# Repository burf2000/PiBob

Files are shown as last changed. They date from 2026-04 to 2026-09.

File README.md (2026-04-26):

# PiBob

> **Work in Progress** — This is v0.1. The design and software are functional but still evolving. Expect rough edges, and contributions are very welcome!

A cheap, 3D-printable robot you can build for under £100. Powered by a Raspberry Pi with dual arms and a head, controlled via a web interface. PiBob uses an Adafruit PCA9685 servo hat to drive 10 servos, with a Flask web app for real-time control and a live camera feed.

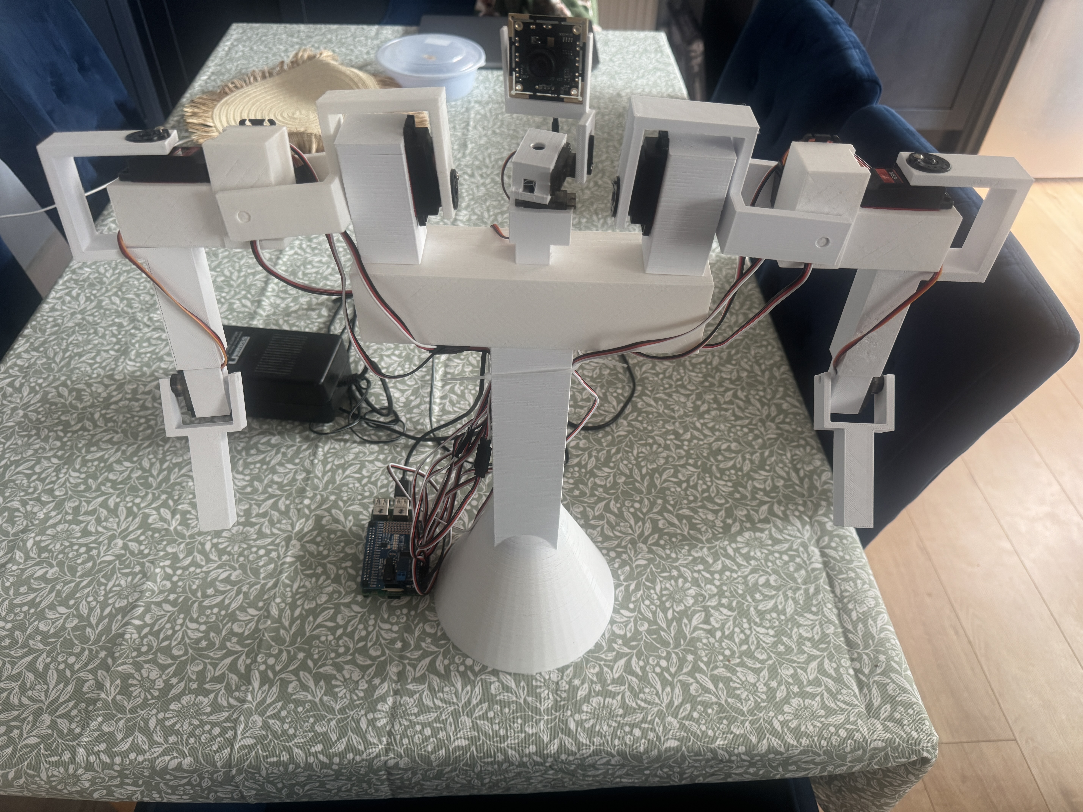
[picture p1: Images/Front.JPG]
PiBob Front View

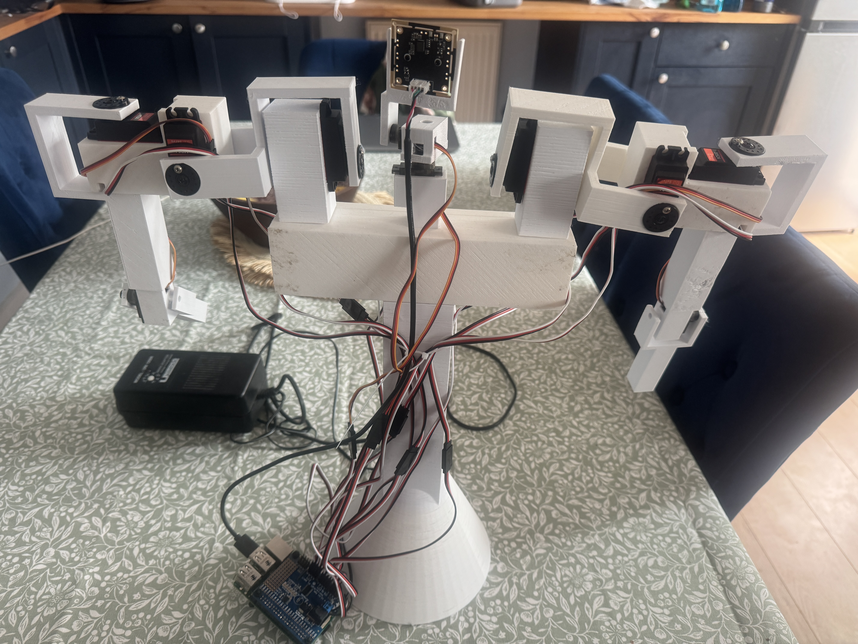
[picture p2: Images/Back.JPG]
PiBob Back View


## Features

- **Web UI** — real-time sliders, enable/disable, reverse direction, pulse width tuning
- **Live camera feed** — streamed directly to the web interface
- **16-channel control** — servo, continuous rotation, or raw PWM modes per channel
- **Safe limits** — configurable min/max per channel, persisted to `config.json`
- **Presets** — save and load servo positions
- **Gestures** — pre-programmed movements with smooth interpolation:
  Wave, Point, Run, Scared, Angry, Celebrate, Shrug, Dab, Fight, Dance
- **Sweep test** — automatically sweep all servos through their range
- **PWM frequency** — adjustable from 24–1526 Hz

## Hardware

See [BOM.md](BOM.md) for the full bill of materials. Key components:

- Raspberry Pi (any model with I2C and USB)
- Adafruit PCA9685 16-channel servo HAT
- 4x Miuzei 9G micro servos (head + smaller joints)
- 6x Miuzei DS3218MG 20KG digital servos (arm joints)
- 1x USB camera module
- 3D printed parts (STL files included)

### Channel Mapping

| Channel | Joint | Notes |
|---|---|---|
| CH2 | Head Rotation | Left/right, full range (0-180) |
| CH3 | Head Tilt | Up/down (50-140) |
| CH4 | Right Bicep | 90 = straight, 180 = fully bent |
| CH5 | Right Arm Rotation | Reversed, side-to-side |
| CH6 | Right Shoulder Lift | Reversed, chicken wing style |
| CH7 | Right Shoulder Rotation | Reversed, arm up/down front |
| CH8 | Left Bicep | Reversed, mirrors right |
| CH9 | Left Arm Rotation | Side-to-side |
| CH10 | Left Shoulder Lift | Chicken wing style |
| CH11 | Left Shoulder Rotation | Arm up/down front |

## 3D Printing & Assembly

All STL files are in the [`STL/`](STL/) folder. Parts were designed in TinkerCAD. PLA works fine for all parts.

### Print List

| Part | File | Qty |
|---|---|-----|
| Desktop Base | `Desktop-Base.stl` | 1 |
| Shoulder Beam | `Shoulder-Beam.stl` | 1 |
| Head Bottom Servo Holder | `Head-BottomServoHolder.stl` | 1 |
| Head Middle Servo Holder | `Head-MiddleServoHolder.stl` | 1 |
| Head Camera Holder | `Head-CameraHolder.stl` | 1 |
| Shoulder Top Servo Holder | `Shoulder-Top-ServoHolder.stl` | 2 |
| Shoulder Left Bracket | `Shoulder-Left-Bracket.stl` | 1 |
| Shoulder Right Bracket | `Shoulder-Right-Bracket.stl` | 1 |
| Shoulder Left Servo Holder | `Shoulder-Left-ServoHolder.stl` | 1 |
| Shoulder Right Servo Holder | `Shoulder-Right-ServoHolder.stl` | 1 |
| Arm Bicep | `Arm-Bicep.stl` | 2 |
| Arm Elbow | `Arm-Elbow.stl` | 2 |
| Arm Forearm | `Arm-Forearm.stl` | 2 |

### Assembly: Body

1. Print `Desktop-Base.stl` — this is the main base of the robot
2. Place `Shoulder-Beam.stl` on top of the base to form the main body

### Assembly: Head

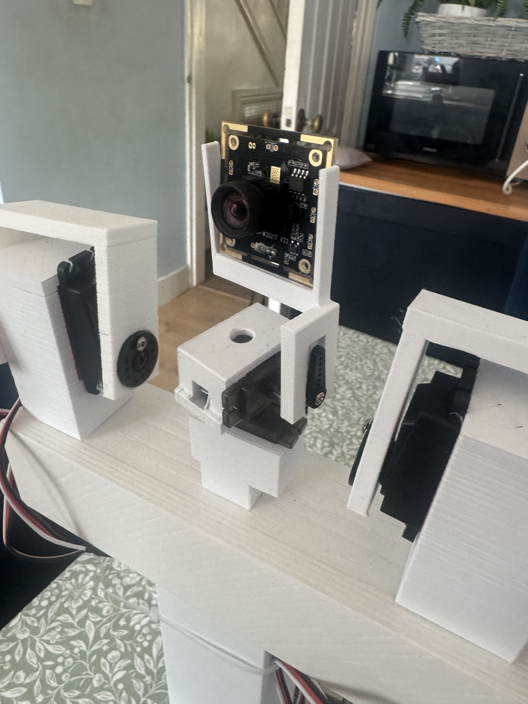
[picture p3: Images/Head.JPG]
Head assembly


1. Fit a small servo into `Head-BottomServoHolder.stl`, then push it into the top of `Shoulder-Beam.stl`
2. Fit another small servo to `Head-MiddleServoHolder.stl`, then attach it to `Head-BottomServoHolder.stl`
3. Slide the USB camera into `Head-CameraHolder.stl` and connect it to `Head-MiddleServoHolder.stl`

### Assembly: Shoulders & Arms

Left and right arms are the same build, except where a Left/Right-specific STL is provided.

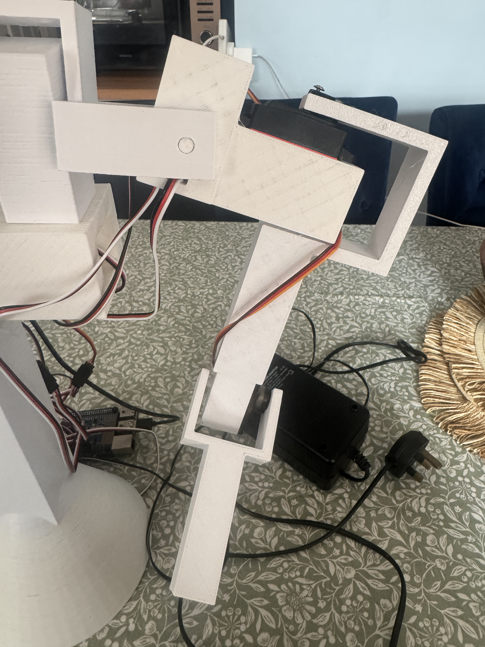
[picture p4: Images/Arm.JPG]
Arm assembly

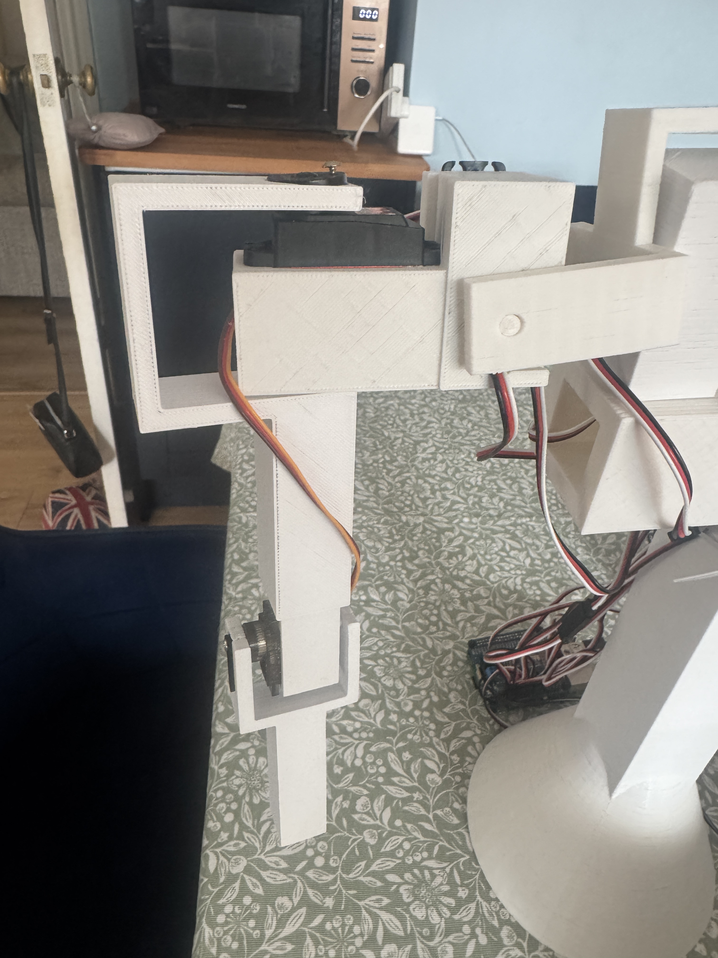
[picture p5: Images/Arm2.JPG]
Arm detail


1. Print 2x `Shoulder-Top-ServoHolder.stl`, fit servos, then push them into `Shoulder-Beam.stl`
2. Print `Shoulder-Left-Bracket.stl` and `Shoulder-Right-Bracket.stl`, fit servos, and attach to the shoulder top servo holders
3. Print `Shoulder-Left-ServoHolder.stl` and `Shoulder-Right-ServoHolder.stl`, fit servos, and attach to the corresponding shoulder brackets
4. Print 2x `Arm-Bicep.stl` and attach to the shoulder servo holders
5. Print 2x `Arm-Elbow.stl`, fit small servos, and attach to the biceps
6. Print 2x `Arm-Forearm.stl` and attach to the elbows

## Setup

### 1. Install dependencies

```bash
pip install -r requirements.txt
```

### 2. Copy files to the Pi

```bash
scp -r app.py requirements.txt youruser@yourpi.local:~/pibob/
```

### 3. Run

```bash
python3 app.py
```

The web UI will be available at `http://yourpi.local:8080`. To use port 80 (requires root):

```bash
sudo PORT=80 python3 app.py
```

### Running as a service

Create `/etc/systemd/system/pibob.service`:

```ini
[Unit]
Description=PiBob Servo Control
After=network.target

[Service]
ExecStart=/usr/bin/python3 /home/youruser/pibob/app.py
WorkingDirectory=/home/youruser/pibob
Restart=always
User=root

[Install]
WantedBy=multi-user.target
```

Then:

```bash
sudo systemctl enable pibob.service
sudo systemctl start pibob.service
```

## API

All endpoints accept JSON via POST.

| Endpoint | Description |
|---|---|
| `GET /` | Web UI |
| `POST /set` | Set channel value `{channel, value, mode}` |
| `POST /mode` | Change channel mode `{channel, mode}` |
| `POST /enable` | Enable/disable channel `{channel, enabled}` |
| `POST /reverse` | Toggle reverse `{channel, reversed}` |
| `POST /pulse` | Set pulse width range `{channel, min_pulse, max_pulse}` |
| `POST /config` | Update channel name/limits `{channel, name?, safe_min?, safe_max?}` |
| `POST /frequency` | Set PWM frequency `{frequency}` |
| `POST /gesture` | Run a gesture `{name}` |
| `POST /sweep` | Start/stop sweep `{active}` |
| `GET /state` | Get current state of all channels |
| `POST /presets/save` | Save preset `{name, state}` |
| `POST /presets/load` | Load preset `{name}` |
| `POST /presets/delete` | Delete preset `{name}` |

## Contributing

Contributions are welcome! Feel free to open issues or submit pull requests.

## License

This project is licensed under the MIT License — see [LICENSE](LICENSE) for details.

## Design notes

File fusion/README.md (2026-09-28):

# PiBob → Fusion 360 assembly

Opens PiBob in Fusion 360 as a jointed assembly generated from the URDF
(`ros2/pibob_description/urdf/pibob.urdf.xacro`). Each joint rotates about the
same pivot and axis as in the URDF, with the URDF limits. `verify/` checks this
against RViz.

```
fusion/
  urdf_to_fusion_data.py        URDF (xacro) -> pibob_fusion.json          (runs on the Mac)
  pibob_fusion.json             generated; committed so Fusion works without Python
  PiBobAssembly/                the Fusion 360 script (PiBobAssembly.py + .manifest)
  preview_pose.py               poses/renders PiBob from the JSON alone (same motion as Fusion)
  verify/                       RViz comparison, mock-Fusion dry run, comparison PNGs, results.json
```

## Run it

1. **Regenerate the JSON** (needed only after the URDF changes; the committed copy matches `main`):
   ```bash
   uv run --with xacro --with numpy fusion/urdf_to_fusion_data.py
   ```
2. **Install the script in Fusion:** open **Utilities → Add-Ins → Scripts and Add-Ins**
   (or press Shift+S). Next to *My Scripts*, click **+**, choose
   `PiBob/fusion/PiBobAssembly`, then select **PiBobAssembly** and click **Run**.
   Fusion runs the script from where it sits in the repo. The script looks for
   `../pibob_fusion.json`, and the STLs are found through relative paths from the
   JSON (`../ros2/pibob_description/meshes/*.stl`). Keep `fusion/` inside the repo
   checkout. If you move it, the script asks you to pick the JSON, and it also
   accepts STLs copied into `fusion/meshes/`.
3. **Wait a few seconds.** A new untitled design opens. When the script finishes,
   a message box shows the joint self-check (see below). The same report is saved
   as `fusion/fusion_check.txt`.
4. **Save it:** use **File → Save** to store it in your Fusion hub, or
   **File → Export → .f3d** to get a local file.

## What you get

- **One component per URDF link** (16 of them: `base_link`, `shoulder_beam`, head ×4,
  and 5 per arm). Every link component sits at the link's zero-pose frame, so its
  **origin is the URDF joint pivot**.
- Inside each link component there is **one sub-component per URDF `<visual>`**,
  named `<link>__<Part>`, for example `r_upper_arm_link__Arm-Bicep`. It is placed at
  the visual `<origin>` and holds the STL as a mesh body, imported in mm inside a
  Base Feature. `upper_arm_link` has three sub-components: the bicep, the fixed
  elbow and the elbow servo. `camera_link` has none; it's just a frame. The sub-components are *Ground to Parent*, so they move with their link.
- **As-built joints** (nothing jumps when they're created):
  - 10 revolute joints, each about the URDF axis through the URDF pivot. Each has
    min/max limits from the URDF and **no rest value**, because a rest value makes
    joints snap back after a drag. Drive them with *Drive Joints*, a *Motion Study*,
    or by dragging.
  - 5 rigid joints for the URDF `fixed` joints. `base_link` is the only grounded
    occurrence.
- **How a revolute joint is built.** Every link component gets a construction
  sketch `<joint>_axis`. It holds a 20 mm construction line starting at the
  component origin (the pivot) and running along the URDF axis, sign included, so
  a −Y axis is drawn towards −Y. The joint is then
  `JointGeometry.createByCurve(line, StartKeyPoint)` with `ZAxisJointDirection`.
  The origin is the start of the line and the rotation axis runs along it. If the
  self-check finds that axis wrong, the script deletes the joint and rebuilds it as
  `createByPoint(child origin)` with `X/Y/ZAxisJointDirection`. It keeps whichever
  version passes, and the report shows which one was used (`[axis-line]` or
  `[point+XYZ]`).
- **Joints use only sketch and construction geometry.** Nothing references a mesh
  or a BRep face or edge.

### Joint self-check (runs automatically in Fusion)

After building, the script drives each revolute joint to 0.3 rad and reads the
child occurrence's world transform before and after. From that it works out the
**real** rotation axis and angle, and checks:

- **Axis error:** the angle between the real axis and the URDF axis. Anything
  over 5° is flagged `WRONG` and triggers the rebuild described above.
- **Pivot drift:** must be within 0.1 mm.
- **Angle turned:** must be 0.3 rad.

It also checks the sign. If Fusion's positive direction is opposite to the URDF's,
it flips that joint's limits and says `Fusion + = URDF -`. Every joint is then set
back to 0. The report is saved as `fusion/fusion_check.txt`.

`NO UPDATE` means Fusion didn't report the move through the API. The self-check
can't judge that joint, so trust *Drive Joints* instead.

## Troubleshooting (found in real Fusion)

- **Joints turn about the wrong axis.** This happened on the first real run:
  the elbow swung left–right instead of up–down, and the shoulder joint next to
  the head did the same. The original build used `createByPoint` plus
  `CustomJointDirection` with a construction-axis proxy. Fusion ignored the custom
  direction and turned the joint about the point's default Z. It's fixed by the
  axis-line construction above, with the point+XYZ fallback. The self-check now
  measures the real axis, so this can't pass silently again. If a joint still
  reports `WRONG` after both attempts, delete the joint and redo it by hand: pick
  the start point of the link's `<joint>_axis` sketch line.
- **Joints snap back after you drag them.** The first build enabled a rest value
  of 0. Rest values are now off. Only the min/max limits are set.

## Arm pivots: on the pins, from the meshes

Every arm joint origin used to be a hand-tuned guess. `shoulder_lift` was 14 mm off
its pin and `arm_rot` was 19 mm off, so parts swung about empty space. Each joint
origin now sits **on the physical rotation feature found in the STLs**, and the
parts have **not moved**: every visual and child-joint origin was re-expressed
against the new joint frame. Zero-pose vertex displacement vs the previous URDF is
**0.0 mm** (`verify/pin_check.py --ref <old json>`).

**What the meshes contain.** `verify/pin_check.py` fits circles to the curved facets
of every STL and classifies each as a boss or a hole from the facet normals:

- **DS3218 holders** (Shoulder-Top-ServoHolder, Shoulder-L/R-ServoHolder) each carry
  a **Ø5.8 × 6.1 mm pin coaxial with the servo shaft**. On the top holder the pin is
  9.5 mm from the end of the 40.2 × 20.5 mm DS3218 pocket, which is the DS3218
  shaft offset.
- **Driven U-brackets** (Shoulder-L/R-Bracket, Arm-Bicep) have, all coaxial: a
  **Ø21 × 2.3 mm horn seat plus a Ø9 hub hole** on one arm, and a **Ø6 pin hole** on
  the other.
- **The 9 g elbow** has a Ø4.7 pin on Arm-Elbow, coaxial with the modelled
  servo's Ø4.8 spline. Arm-Forearm has a Ø7 hub hole and a Ø5 pin hole.

Each joint origin is the pin's root centre (where it leaves its holder). The axis
is the pin axis, **0.000° from the URDF axis in every case**, so the axis signs and
limits are unchanged.

| joint (L = R mirrored) | pin | old → new origin, world mm | moved by, mm | origin → pin axis |
|---|---|---|---|---|
| shoulder_rot | Shoulder-Top-ServoHolder Ø5.8 | (0, ±85, 365) → (0, ±98.45, 369.9) | 14.3 | 0.000 mm |
| shoulder_lift | Shoulder-ServoHolder Ø5.8 (X) | (0, ±145, 385) → (−13.45, ±154.5, 374.55) | 19.5 | 0.000 mm |
| arm_rot | Shoulder-ServoHolder Ø5.8 (Z) | (4, ±225, 340) → (3.55, ±205.6, 394.45) | 57.8 | 0.000 mm |
| bicep | Arm-Elbow Ø4.7 (+ servo spline) | (4, ±225, 260) → (4, ±218.5, 259.9) | 6.5 | 0.000 mm |
| head_pan / head_tilt | 9 g servo spline Ø4.8 | unchanged | 0 | 0.000 mm |

**The mating part's hole is not always on the pin: seating errors in the URDF.**
Holding the pin still, `pin_check.py` sweeps each joint (up to ±45° within limits)
and measures how far the other part's pin hole moves. It also measures how far that
hole sits off the pin axis at zero pose:

| joint | hole off pin axis at zero pose | hole drift over the sweep | what that means |
|---|---|---|---|
| head_pan, head_tilt | 0.00 mm | 0.00 mm | concentric ✔ |
| shoulder_lift | bracket's Ø6 / Ø9 / Ø21 are 9.5 mm off the holder pin | 0.0 mm (the child owns the pin) | the pin sits inside the bracket wall |
| shoulder_rot | bracket's Ø6 / Ø9 / Ø21 are 5.6 mm below the top-holder pin | 4.3 mm | bracket seated 5.6 mm too low |
| arm_rot | bicep's Ø6 / Ø9 / Ø21 are 0.8–0.9 mm off | 0.64 mm | small |
| bicep | forearm's Ø5 / Ø7 are 1.1 mm above the elbow pin | 0.84 mm | small |

These are part-placement errors, not pivot errors. The joints now turn about the
pins, but the bracket (shoulder_rot) and the servo holder (shoulder_lift) were seated
by eye 5.6 mm and 9.5 mm away from where their holes meet the pins. No 180° flip
of either part fixes it; I tested all three. Re-seating them means translating the
part perpendicular to the axis, which *does* move geometry at zero pose, so it isn't
applied here:

- bracket visual only (in `*_shoulder_rot_link`): +5.6 mm Z;
- shoulder servo holder and everything below it (`*_shoulder_lift_link` subtree):
  3.3 mm towards the body centre and −3.45 mm Z, onto the bracket's (re-seated)
  holes;
- bicep, elbow and forearm (`*_upper_arm_link` subtree): about (0.5, 0.7, 0) mm onto
  the holder pin;
- forearm (`*_forearm_link`): −1.1 mm Z.

Close-ups: `verify/pins/<joint>.png` shows lower limit / 0 / upper, only the two
parts at the joint, looking down the pin. The red dot and line mark the pin axis
through the joint origin. The green ring is the child's pin hole, slid into the
pin's plane. Numbers are in `verify/pin_check.json`.

## The head: servos and where the pivots come from

The original head joint origins were rough guesses, and the three head parts
floated with gaps. The head is now seated from the holder STL geometry, with a 9 g
servo modelled in each servo pocket.

**Servo size, from the meshes.** Head-BottomServoHolder, Arm-Elbow (the same part),
and Head-MiddleServoHolder each have a rectangular servo pocket:

| holder | pocket L × W × depth | other features |
|---|---|---|
| Head-BottomServoHolder / Arm-Elbow | 23.0 × 12.2 × 17.25 mm, open on one face | cable slot at one end; Ø4.7 pivot pin on the opposite face, **coaxial with a shaft 5.85 mm from the pocket end** |
| Head-MiddleServoHolder | 23.0 × 12.1 × 18.0 mm, open to one side | cable slot at one end; Ø7 hub hole and a 7 mm-wide horn groove in its floor |
| Head-CameraHolder | none | side arm with a Ø7 hub hole and a 7 mm horn groove on its outer face |

A 23 × 12.2 mm pocket is an **SG90 / MG90S-class 9 g micro servo**: 22.8 × 12.2 mm
body, 32.2 mm tab span, output spline Ø4.8. That agrees with the BOM ("4 × Miuzei 9G":
head pan, head tilt, and the two elbows). The model `ros2/pibob_description/meshes/Servo-9g.stl`
comes from `ros2/pibob_description/scripts/make_servo_stl.py`. It's a body box, a
tab plate and a spline. Its origin is **on the output shaft at the body's top face**,
so a servo visual's `<origin>` in the URDF *is* the shaft axis. The shaft offset
(5.85 mm) is taken from the holder pin; the tab height (16 mm) is the datasheet value.

The xacro gets a reusable `<xacro:servo_9g xyz rpy/>` visual macro, used 4 times:
pan, tilt, and both elbows. The six DS3218 arm servos aren't modelled. The arms
were already right and no arm joint moved. The elbow servos drop in because the
elbow holder is the same part: the elbow servo shaft lies on the bicep axis to
0.1 mm.

**How the head stacks** (derived from the mating features, and matching the photos
in `Images/`):

1. `head_base_link` (new, fixed to the beam) holds Head-BottomServoHolder with
   its **pocket facing up**. Its bottom face sits on the beam top, and its pivot
   pin drops into the beam's 20 × 20 mm head hole. The **pan servo** stands in the
   pocket with its tabs on the holder's top face.
2. `head_pan_joint` is on the pan servo's shaft axis at its top face, 62.2 mm above
   the beam centre (was 45 mm, a guess).
3. `head_pan_link` holds Head-MiddleServoHolder. The floor's hub hole is on the pan
   shaft, and its underside sits on the pan servo's top face. The **tilt servo**
   sits in its side pocket with the shaft pointing to the robot's left. This link
   used to carry the bottom holder, which doesn't turn with pan.
4. `head_tilt_joint` is on the tilt servo's shaft axis at its top face:
   (−3.15, 17.2, 11.05) mm from the pan pivot (was (0, 0, 30) mm, a guess).
5. `head_tilt_link` holds Head-CameraHolder. The side arm's hub hole is on the
   tilt shaft and its inner face sits on the tilt servo's top face. `camera_link`
   is a fixed frame at the centre of the camera board. Before, the camera holder
   was the only part on the tilt side and the middle holder turned with tilt.

Checks (`preview_pose.py --servo-check / --contact-check / --pivot-check`, also in
`verify/results.json`):

- Pan and tilt pivots are **0.000 mm off their servo's shaft axis, 0.000 mm from its
  top face, 0.000° axis error**. Each also sits in the Ø7 hub hole of the part it
  drives, 3.5 mm from the part's surface (the hole radius).
- These contact pairs all have a **0.0 mm gap** (the last is 0.002 mm): beam ↔
  bottom holder, bottom holder ↔ pan servo, pan servo ↔ middle holder, middle
  holder ↔ tilt servo, tilt servo ↔ camera holder.
- The camera holder clears the middle holder by more than 6 mm across the whole
  tilt range (−40° to +50°).

**Head vs the photos (checked again, from a Fusion user's viewpoint).** Nothing
floats and nothing interpenetrates by more than 0.2 mm at zero, pan ±90° or the
tilt limits. Every head contact is 0.0 mm. There are two visible differences from
`Images/Front.JPG`, `Back.JPG` and `Head.JPG`, and **neither can be fixed from the
repo STLs**:

1. The printed head base has a peg going down into the beam. This STL's peg is on
   the end face at a right angle to its servo pocket, so with the pan shaft
   vertical the peg points sideways.
2. The photos suggest the printed middle holder is taller than wide, with the
   tilt servo standing upright. The STL is a 38 × 20 × 20 box whose pocket runs
   front-to-back under its Ø7 top hole.

The printed head parts look like a different revision from the STLs in
`STL/` and `meshes/`. Export the current head parts and they can be dropped in
(see *Editing / swapping a part*); the pivots follow their hub holes.

**One thing to check on the robot.** In this orientation, Head-BottomServoHolder's
square peg (the end that, on the elbow, plugs into the bicep) sticks out
**sideways**, to the robot's right, just above the beam. The photos show the printed
head base with a peg going *down* into the beam, which this STL can't do while its
pocket faces up. Either the head-base STL in the repo differs from the printed one,
or the peg is unused on the head. The pivots don't depend on it: they come from the
servo and hub features, which all agree. If the printed part differs, export it
and swap it in (see below).

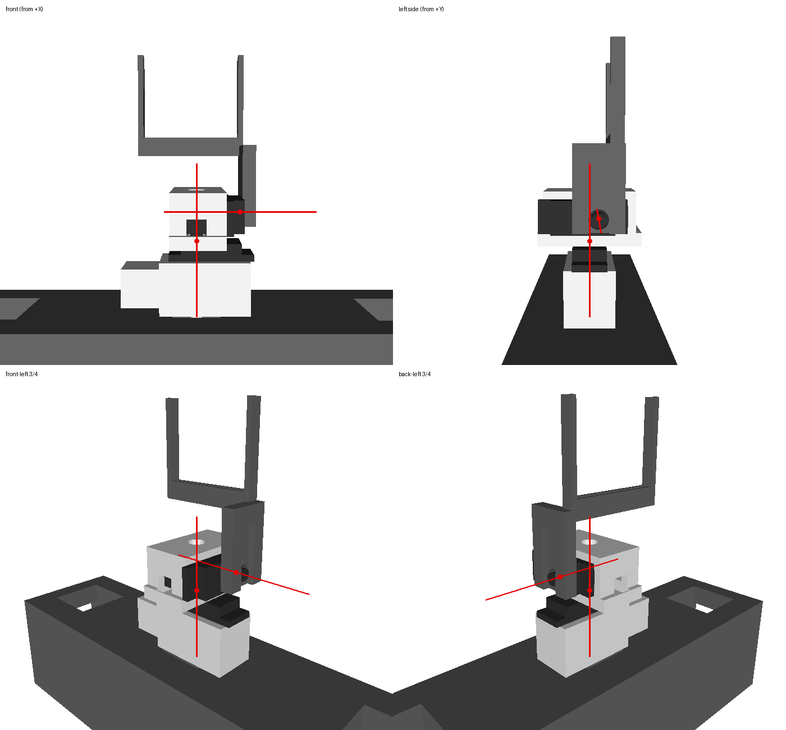
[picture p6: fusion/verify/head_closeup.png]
head close-up


## Editing / swapping a part

The joints use only link-component construction geometry, so you can replace a
part's geometry without breaking any joint:

1. Expand the link component, for example `r_upper_arm_link`, then its part
   sub-component, for example `r_upper_arm_link__Arm-Bicep`.
2. **Activate the part sub-component** and insert the new body into it, from a
   STEP/f3d via *Insert → Insert Derive / Insert into current design*, or by modelling
   it there directly. The sub-component's frame **is the STL's native frame**, the
   coordinates the part was modelled in. A STEP export of the same TinkerCAD or
   Fusion part therefore lands in the right place without any moving.
3. Delete the old mesh body. The joints are unaffected. Drive a joint to confirm.
4. If the new part is modelled in a different frame, move the *body* inside the
   part sub-component. Don't move the link component: its origin is the pivot.

To change a **pivot or axis**, edit the URDF, regenerate the JSON and re-run the
script. Moving a link component's origin in Fusion moves the pivot.

**Mesh bodies are not editable solids.** They are fine for rendering, interference
checks and motion studies, but you can't fillet, shell or sketch on them.
*Mesh → Convert Mesh* (prismatic/faceted, and it may need the mesh repaired first)
only suits simple, low-poly parts. Most of PiBob's printed brackets are
TinkerCAD-simple, so they may convert. The practical route for real edits is
still to re-export the original parts as STEP from TinkerCAD and swap them in as
above.

## Verification (what was checked, and how to re-run it)

All of these come from the same `pibob_fusion.json` the Fusion script reads.

1. **Numeric TF match with RViz.** `verify/run_verification.py` drives the
   `pibob-rviz` container's `/joint_states` (its `rviz_reference.py` replaces the
   slider GUI) at 12 poses: zero, each revolute joint alone at +45° (±20° for
   `shoulder_lift`, its limit), and one combined 10-joint pose. At each pose it
   compares every link's TF from `robot_state_publisher` with
   `preview_pose.pose_world()`. `pose_world()` rotates each child subtree about
   the joint's world pivot and axis, which is exactly what a Fusion revolute joint
   does. **Result: max error 0.0000 mm / 0.0000° for every link in every pose**
   (including the reworked head).
2. **Visual match.** For each pose it screenshots RViz and renders the preview from
   the same camera (RViz Orbit model, 45° FOV). It saves
   `verify/<pose>.png` as *preview | RViz | overlay* for two views. For zero,
   head_pan +45° and head_tilt +45° there are also head close-ups (front, and side
   over the left shoulder) in `verify/<pose>_head.png`. In the preview, the moving
   subtree is orange and the pivot and axis are red. In the overlay, red is preview
   only and cyan is RViz only. **Silhouette IoU is 0.992–0.996 in every pose and
   view, and 0.997–0.998 for the head close-ups.** The remainder is edge
   anti-aliasing: no part detaches and nothing is mirrored.
   `verify/head_closeup.png` is a head-only sheet with the pan and tilt axes drawn.
3. **Mock-Fusion dry run.** `verify/mock_fusion_run.py` runs `PiBobAssembly.py`
   against a small mock of the adsk API that includes an as-built-joint solver. It
   checks that:
   - the script runs end to end;
   - every mesh vertex lands where the preview puts it: **0.000000 mm** at zero and
     at the combined pose, driven through the mock joints;
   - the self-check and limit-sign logic work under **both** Fusion sign conventions;
   - with the real-Fusion wrong-axis bug injected, the self-check flags every
     non-vertical joint;
   - when only the axis-line construction is broken, the fallback rebuild fixes
     every joint and the pose matches to 0.000000 mm.

   It proves our code and maths, not that real Fusion accepts each call. The
   mock passed before the first real-Fusion run too, and that run still hit the
   wrong-axis bug.
4. **Pivot vs servo holder** (`preview_pose.py --pivot-check`). This is the distance
   from each joint pivot to the nearest surface of the parent-side and child-side
   meshes, plus how far the pivot is outside the part's bounding envelope (0 means
   it's within the part, for example in its servo pocket, which is empty space in
   the STL):

   | joint | parent part: surface / outside envelope | child part: surface / outside envelope |
   |---|---|---|
   | head_pan | beam + bottom holder + **pan servo** 0.0 / 0 mm | Head-MiddleServoHolder 3.5 / 0 mm (in its hub hole) |
   | head_tilt | middle holder + **tilt servo** 0.0 / 0 mm | Head-CameraHolder 3.5 / 0 mm (in its hub hole) |
   | shoulder_rot / lift / arm_rot / bicep | see *Arm pivots* above: each origin is on its pin, 0.000 mm | |

   The "parent part" now counts every link fixed to the parent. For example, the pan
   servo lives in `head_base_link`, which is fixed to the beam. The head pivots sit
   on their servo's top face. The arm pivots now sit on their pins.
   (Correction: an earlier version of this README called the 20–25 mm
   `shoulder_lift` / `arm_rot` distances "servo pockets". They were real pivot
   errors.)

Re-run everything:

```bash
./ros2/docker/dev.sh     # or: docker run -d --name pibob-rviz -p 6080:6080 pibob-ros2-rviz:humble
uv run --with numpy --with trimesh --with pillow fusion/verify/run_verification.py
uv run --with numpy --with trimesh --with pillow fusion/verify/mock_fusion_run.py
uv run --with numpy --with trimesh --with pillow fusion/preview_pose.py --pivot-check
uv run --with numpy --with trimesh --with pillow fusion/preview_pose.py --servo-check
uv run --with numpy --with trimesh --with pillow fusion/preview_pose.py --contact-check
git show <old-commit>:fusion/pibob_fusion.json > fusion/verify/_ref.json   # optional, for the zero-pose diff
uv run --with numpy --with trimesh --with pillow fusion/verify/pin_check.py --ref fusion/verify/_ref.json
```

The container must include the current URDF and `Servo-9g.stl`. After changing
either, rebuild the image (`./ros2/docker/dev.sh --build`).

`run_verification.py` replaces the container's slider GUI with its own
publisher. Restart the container to get the sliders back.

## Uncertain Fusion API spots (look here first if it errors)

The script was written against the documented API but has **not** been run in real
Fusion. Each of the following is wrapped or reported where possible:

1. **`comp.meshBodies.add(path, MeshUnits.MillimeterMeshUnit, baseFeature)` inside
   `baseFeature.startEdit()/finishEdit()` on a non-root, non-active component.** This
   is the mesh import. If it fails, try activating the component first, or switch
   the design to Direct (`design.designType = DirectDesignType`). In a Direct design
   the base feature isn't needed.
2. **`asBuiltJoints.createInput(child, parent, None)` for rigid joints.** The docs
   say geometry is optional for rigid joints. The script falls back to the child's
   origin point if Fusion rejects `None`.
3. **`JointGeometry.createByCurve(sketchLineProxy, StartKeyPoint)` plus
   `ZAxisJointDirection`.** This assumes a straight curve's joint Z runs along the
   line. The self-check verifies it, and if it's wrong the joint falls back to
   `createByPoint` with `X/Y/ZAxisJointDirection`. (`CustomJointDirection` with a
   construction-axis proxy was **proven not to work**; see Troubleshooting.)
4. **`jointMotion.rotationValue` updating `occurrence.transform2` immediately**
   during the self-check. The script calls `adsk.doEvents()` after setting the
   value. If the transform doesn't update, the report says `NO UPDATE`. The joints
   are probably still fine, so check them with Drive Joints.
5. **`occurrence.isGroundToParent`** on the part sub-occurrences (wrapped in
   try/except, so it's cosmetic). Without it you could drag a part away from its
   link by hand.
6. **The manifest** uses `"autodeskProduct": "Fusion"`, which current Fusion writes.
   Very old builds expected `"Fusion360"`.
7. Units: all API lengths are **cm** (metres × 100, done in `matrix_from_json`).
   Matrices are filled with `setCell(row, col)`, so there is no row- or
   column-major ambiguity. Angles are radians.

## Known limits

- STLs import as mesh bodies. See *Editing / swapping a part*.
- There are no materials or appearances. URDF colours are in the JSON (`rgba`) but
  aren't applied.
- Collisions and inertias aren't used, since the URDF has none.
- The Fusion model is the URDF's zero pose, which is PiBob's home pose (every servo
  at 90°).

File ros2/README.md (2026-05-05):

# PiBob ROS 2

Two packages:

- **`pibob_description`** — URDF (xacro), STL meshes, RViz config, display launch.
- **`pibob_driver`** — Python node that bridges `sensor_msgs/JointState` to PiBob's existing Flask servo API.

The driver POSTs to the Flask app already running on the Pi (`servo-control.service`),
so you don't need ROS on the Pi. Run ROS on your dev machine and aim it at `pibob.local`.

## Build

```bash
mkdir -p ~/pibob_ws/src
ln -s $(pwd)/pibob_description ~/pibob_ws/src/
ln -s $(pwd)/pibob_driver      ~/pibob_ws/src/
cd ~/pibob_ws
colcon build --symlink-install
source install/setup.bash
```

Tested with ROS 2 Humble / Jazzy.

## View the model in RViz

```bash
ros2 launch pibob_description display.launch.py
```

The `joint_state_publisher_gui` sliders let you pose the robot virtually.

## Drive the real robot

Make sure the Flask service is up: `http://pibob.local/` should load.

```bash
ros2 launch pibob_driver bringup.launch.py
```

Send commands by publishing to `/joint_commands`:

```bash
ros2 topic pub --once /joint_commands sensor_msgs/JointState \
  '{name: ["head_pan_joint", "head_tilt_joint"], position: [0.5, -0.2]}'
```

To let the GUI slider drive the real robot, remap on launch:

```bash
ros2 launch pibob_driver bringup.launch.py
ros2 run joint_state_publisher_gui joint_state_publisher_gui \
  --ros-args -r joint_states:=/joint_commands
```

## Configuration

Joint → channel mapping, sign and safe limits live in
`pibob_driver/config/joint_map.yaml`. The `sign` field is your get-out for
direction mismatches; `min_deg`/`max_deg` are clamped before each POST as a
safety net on top of the Flask app's own limits.

## What needs calibration

The URDF link offsets (origin xyz/rpy on each joint) are approximate. To
sharpen visual fidelity, measure the real frame and update the `<origin>`
tags in `urdf/pibob.urdf.xacro`. Joint limits already match the safe ranges
in `app.py` and should not need changing.

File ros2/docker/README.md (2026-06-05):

# PiBob ROS 2 + RViz (browser) — Docker

Run the PiBob ROS 2 stack in a container and **see the robot in RViz in your
browser**, move the joint sliders to pose it, and optionally drive the **real**
PiBob with the same sliders.

No ROS install needed on your Mac — only Docker.

## Quick start

```bash
cd ros2/docker
docker compose up --build
```

Then open **http://localhost:6080/vnc.html** and click **Connect**. You'll see a
Linux desktop with **RViz** showing the PiBob model and a **Joint State
Publisher** window of sliders. Drag a slider → the model moves in RViz. A
**taskbar** along the bottom lists every window — click it to restore a
minimised RViz or slider window.

> **If it looks small / has scrollbars:** open the noVNC settings (the little
> toolbar tab on the left edge) → **Settings → Scaling Mode → Local Scaling**,
> or just open **http://localhost:6080/vnc.html?resize=scale** so the desktop
> scales to fill your browser window. The desktop is 1920×1080 by default;
> override with `GEOMETRY` (e.g. `GEOMETRY=2560x1440x24`).

First build takes a few minutes (pulls `ros:humble-desktop`); later runs are
instant.

## Drive the real robot too

```bash
cd ros2/docker
CONTROL_REAL=true docker compose up
```

Now the same sliders also POST to the physical PiBob's Flask `/set` API, so the
RViz model and the real servos move together.

Point at a specific robot (the IP, not `pibob.local`, because mDNS does not
resolve inside the container):

```bash
CONTROL_REAL=true BASE_URL=http://192.168.20.227 docker compose up
```

> Tip: PiBob's DHCP address can change. Check it with
> `dscacheutil -q host -a name pibob.local` on the Mac, or give it a static
> lease. Make sure the robot's Flask UI is reachable first (open
> `http://pibob.local` in a browser).

## Live-edit the URDF (hot reload)

Tuning the model? Run in dev mode and edits to the xacro auto-reload in RViz —
no rebuild:

```bash
chmod +x ros2/docker/dev.sh   # first time
./ros2/docker/dev.sh          # add --build after Dockerfile changes
```

Then open **http://localhost:6080/vnc.html**, edit
`ros2/pibob_description/urdf/pibob.urdf.xacro` on your Mac, and **save** — RViz
redraws in ~12 s (the container re-runs xacro and bounces the launch; a syntax
error is logged and the last good model is kept). This is why the Docker route
beats native Mac viewers: the container has ROS + xacro + the package, so
`package://` meshes and the xacro macro just work.

Under the hood it's the same image with two extras: the `urdf/` dir is
volume-mounted from the host, and `WATCH=1` turns on the file-watcher (see
`entrypoint.sh`). `docker logs -f pibob-rviz` shows reloads and any xacro errors.

## How it works

- `robot_state_publisher` loads the URDF from `pibob_description`.
- `joint_state_publisher_gui` provides the sliders → publishes `/joint_states`.
- `rviz2` renders the model from the URL + TF (config: `pibob_description/rviz/pibob.rviz`).
- With `CONTROL_REAL=true`, `servo_bridge` subscribes to that same
  `/joint_states` (remapped from `joint_commands`) and POSTs each joint to the
  robot. Joint→channel mapping and safe limits live in
  `pibob_driver/config/joint_map.yaml`.

RViz is rendered inside the container with software OpenGL (Mesa llvmpipe) and
streamed to your browser over noVNC — the reliable way to get RViz GUI out of a
Linux container on macOS (XQuartz/X11 forwarding is unreliable with RViz's
OpenGL).

## Without compose (plain docker)

```bash
# from the ros2/ dir
docker build -f docker/Dockerfile -t pibob-ros2-rviz:humble .
docker run --rm -p 6080:6080 -e CONTROL_REAL=false pibob-ros2-rviz:humble
```

## Run ROS 2 commands inside the running container

```bash
docker exec -it pibob-rviz bash -lc 'source /ws/install/setup.bash && ros2 topic echo /joint_states'
```

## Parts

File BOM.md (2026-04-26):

# PiBob - Bill of Materials

| Qty | Component | Notes |
|-----|---|---|
| 1 | Raspberry Pi | Main controller |
| 1 | Adafruit PCA9685 16-Channel Servo HAT | I2C PWM/servo driver |
| 4 | Miuzei 9G Micro Servo (Metal Gear, 180°) | Head rotation, head tilt, and smaller joints |
| 6 | Miuzei DS3218MG 20KG Digital Servo | High torque, full metal gear, waterproof, 270° control angle — used for arm joints |
| 1 | 1MP USB Camera Module (OV9732) | USB 2.0, 1/4" sensor, manual focus — used for live video feed |
| 10 | Servo Extension Cables | Connecting servos to the PCA9685 HAT |
| 1 | 6V Universal Power Supply | Powers the servos via the PCA9685 HAT screw terminal |
| - | 3D Printed Parts | Designed in TinkerCAD |

**Target build cost: under £100**

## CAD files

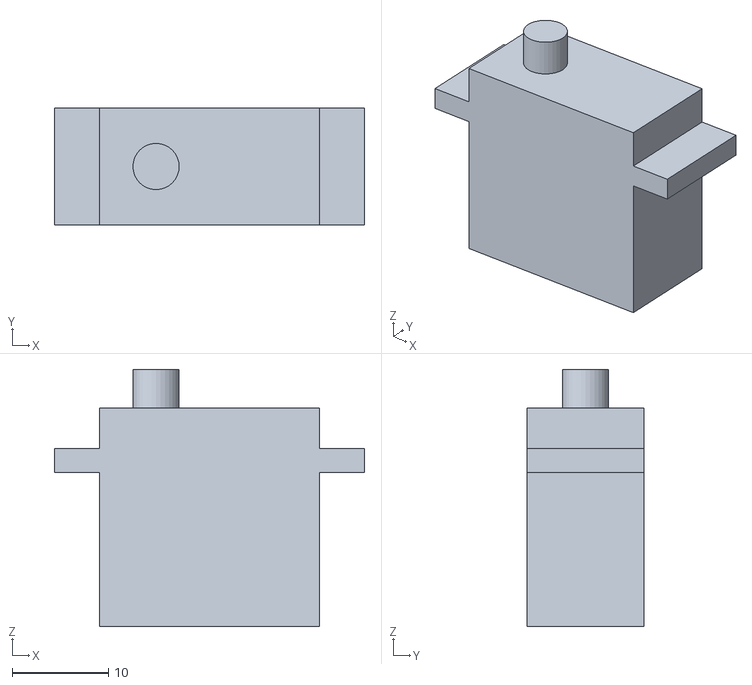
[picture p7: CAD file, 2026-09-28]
ros2/pibob_description/meshes/Servo-9g.stl
32.2 x 12.2 x 26.7

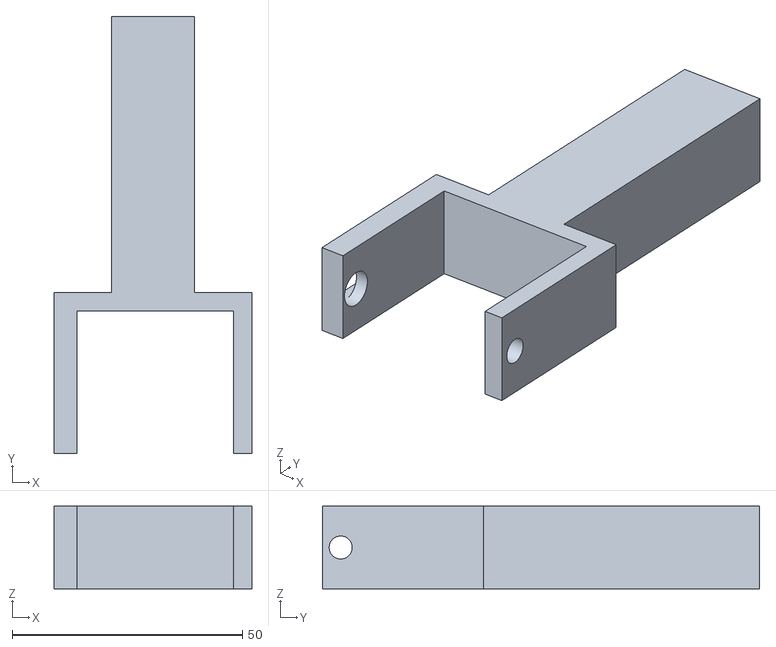
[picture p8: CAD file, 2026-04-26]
ros2/pibob_description/meshes_backup/Arm-Forearm.stl
43.0 x 95.0 x 18.0

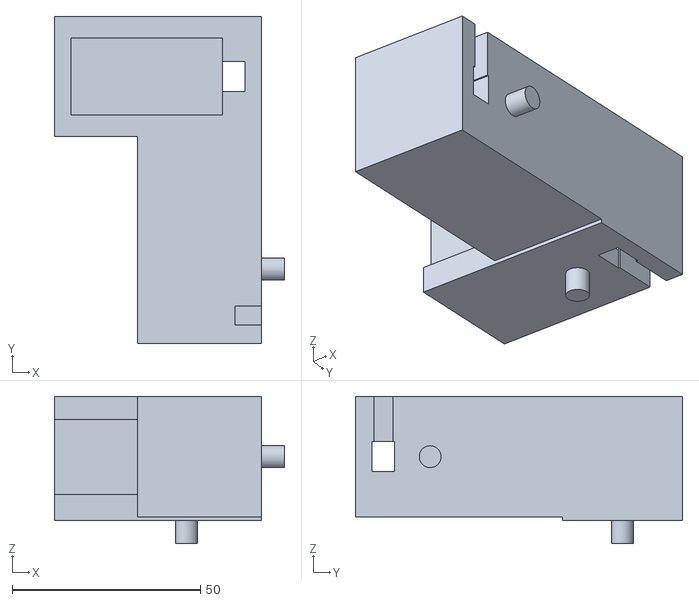
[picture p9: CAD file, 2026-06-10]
ros2/pibob_description/meshes/Shoulder-Left-ServoHolder.stl
61.1 x 87.0 x 39.1

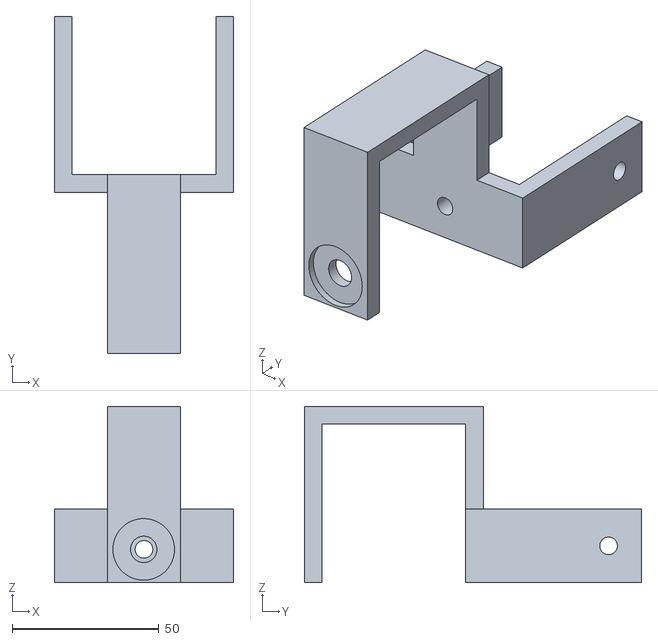
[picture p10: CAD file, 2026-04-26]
ros2/pibob_description/meshes_backup/Shoulder-Left-Bracket.stl
61.0 x 115.0 x 60.0

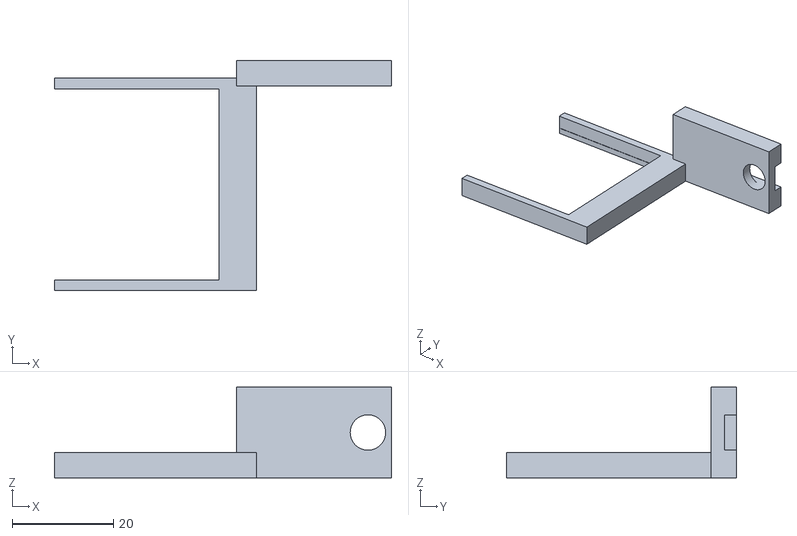
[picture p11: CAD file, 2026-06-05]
ros2/pibob_description/meshes/Head-CameraHolder.stl
66.7 x 45.5 x 18.0

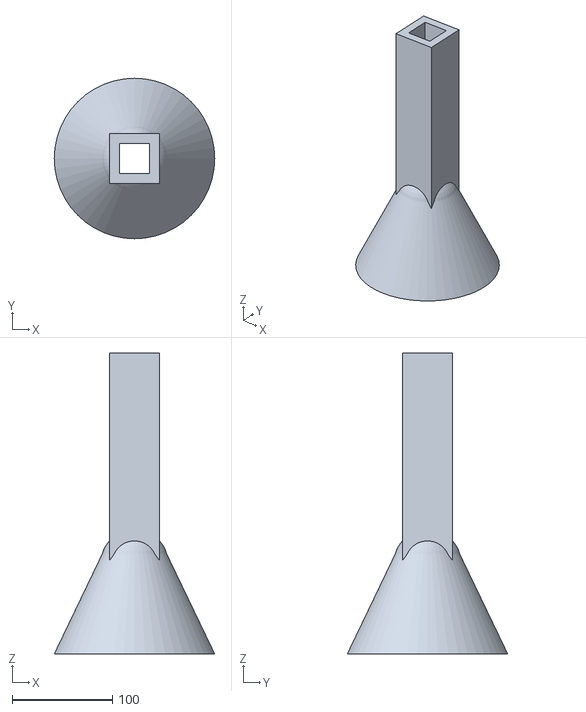
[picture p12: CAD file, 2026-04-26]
ros2/pibob_description/meshes_backup/Desktop-Base.stl
160.0 x 160.0 x 300.0

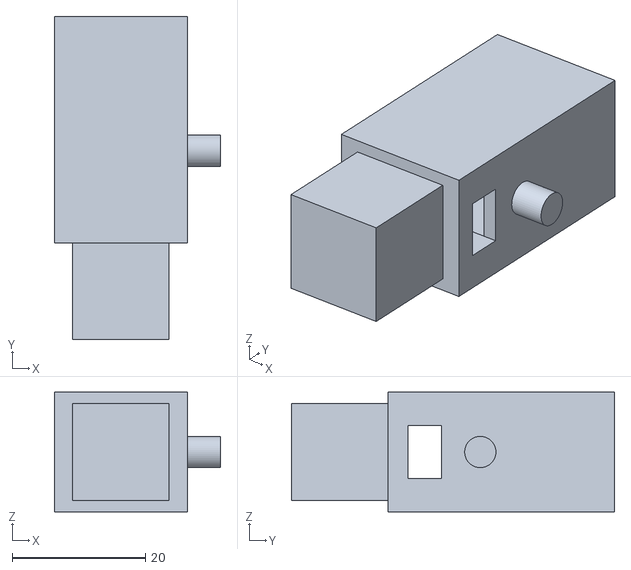
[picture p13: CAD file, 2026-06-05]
ros2/pibob_description/meshes/Arm-Elbow.stl
25.0 x 48.5 x 18.0

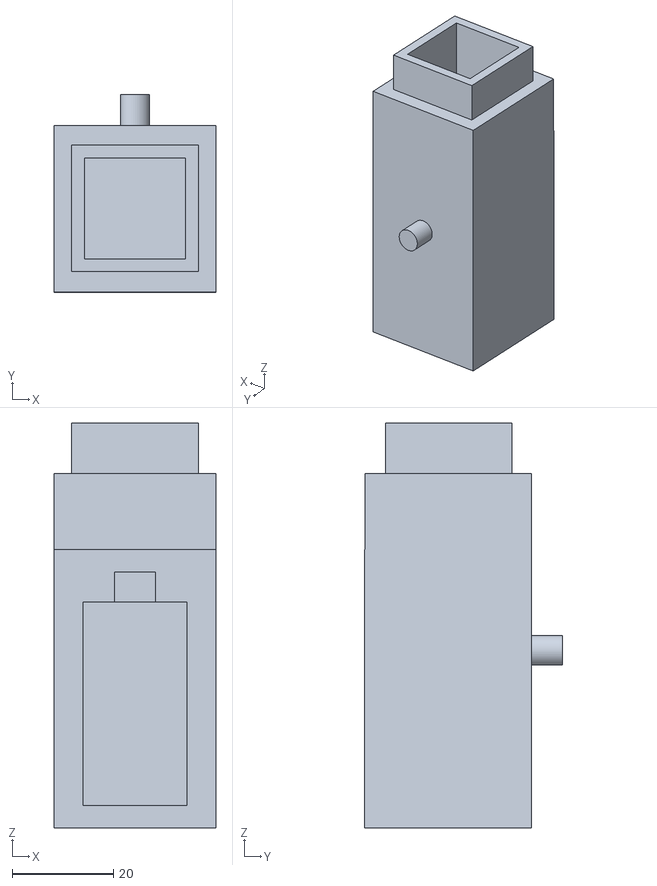
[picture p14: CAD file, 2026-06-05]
ros2/pibob_description/meshes/Shoulder-Top-ServoHolder.stl
32.0 x 39.1 x 80.0

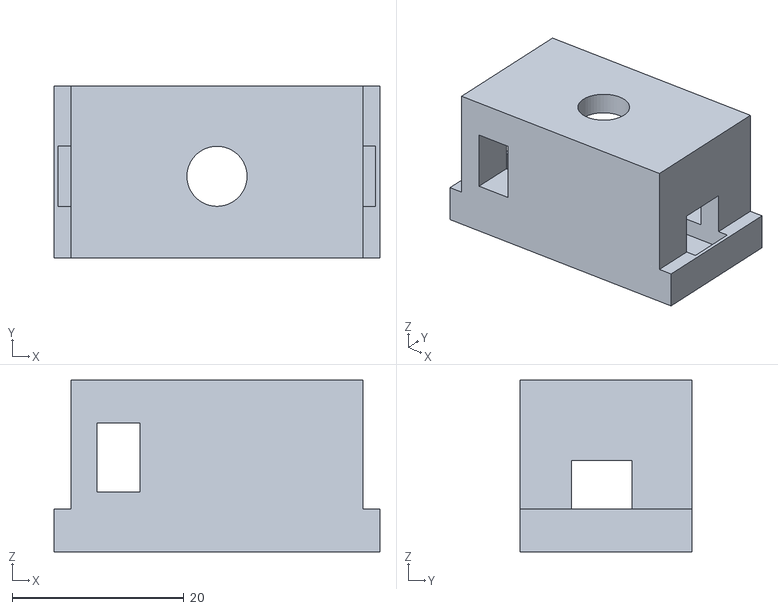
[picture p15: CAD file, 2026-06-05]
ros2/pibob_description/meshes/Head-MiddleServoHolder.stl
38.0 x 20.0 x 20.0

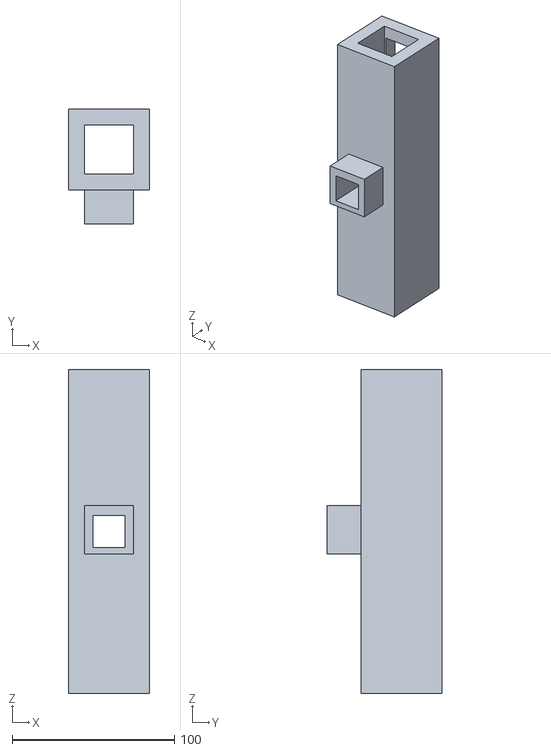
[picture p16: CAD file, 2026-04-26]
ros2/pibob_description/meshes_backup/Shoulder-Beam.stl
50.0 x 71.0 x 200.0

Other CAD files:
ros2/pibob_description/meshes_backup/Shoulder-Left-ServoHolder.stl
ros2/pibob_description/meshes/Shoulder-Right-ServoHolder.stl
ros2/pibob_description/meshes_backup/Head-BottomServoHolder.stl
ros2/pibob_description/meshes_backup/Shoulder-Top-ServoHolder.stl
ros2/pibob_description/meshes/Head-BottomServoHolder.stl
ros2/pibob_description/meshes_backup/Shoulder-Right-Bracket.stl
ros2/pibob_description/meshes/Shoulder-Beam.stl
ros2/pibob_description/meshes_backup/Shoulder-Right-ServoHolder.stl
ros2/pibob_description/meshes/Arm-Bicep.stl
ros2/pibob_description/meshes/Arm-Forearm.stl
ros2/pibob_description/meshes/Desktop-Base.stl
ros2/pibob_description/meshes/Shoulder-Left-Bracket.stl
ros2/pibob_description/meshes/Shoulder-Right-Bracket.stl
ros2/pibob_description/meshes_backup/Arm-Bicep.stl
ros2/pibob_description/meshes_backup/Arm-Elbow.stl
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

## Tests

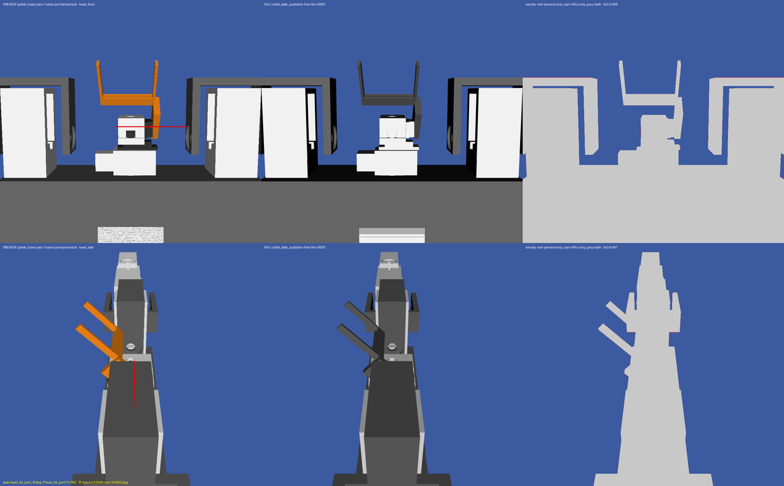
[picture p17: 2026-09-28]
fusion/verify/head_tilt_joint_45deg_head.png

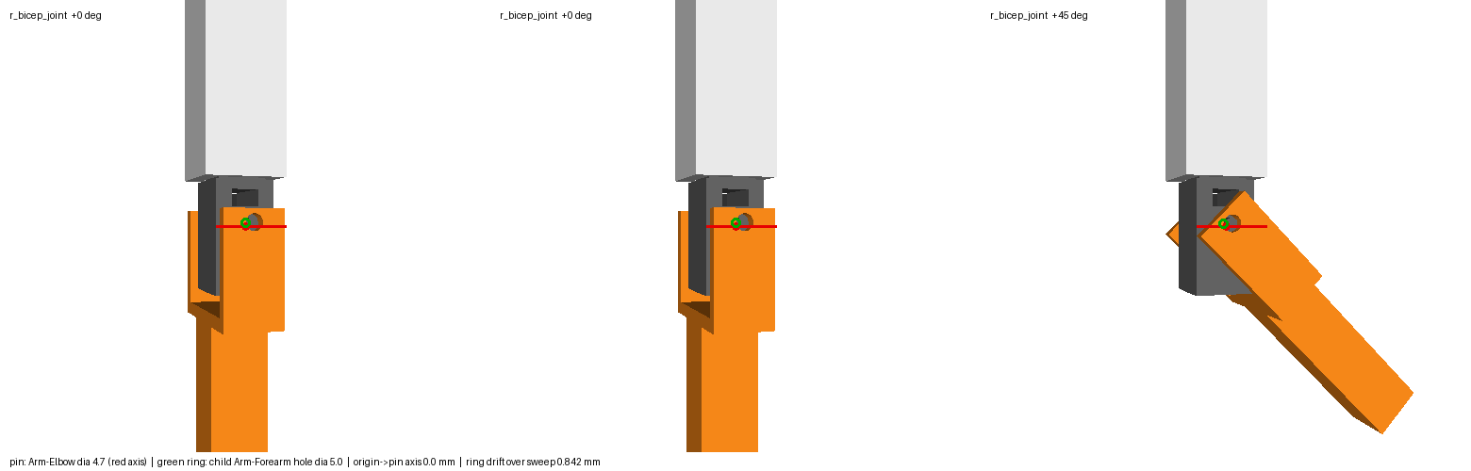
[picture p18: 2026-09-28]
fusion/verify/pins/r_bicep_joint.png

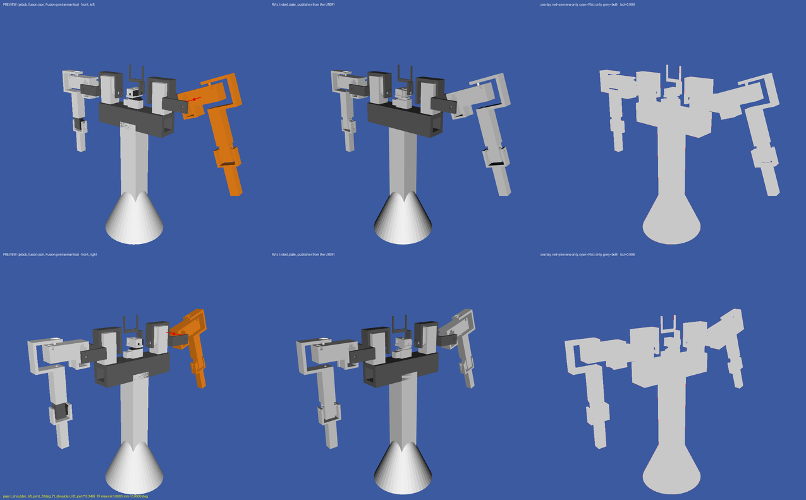
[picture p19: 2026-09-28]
fusion/verify/l_shoulder_lift_joint_20deg.png

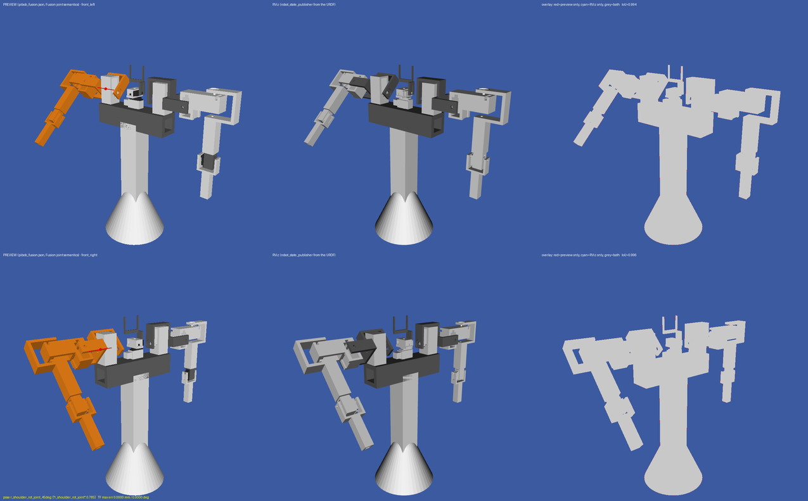
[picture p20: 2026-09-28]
fusion/verify/r_shoulder_rot_joint_45deg.png

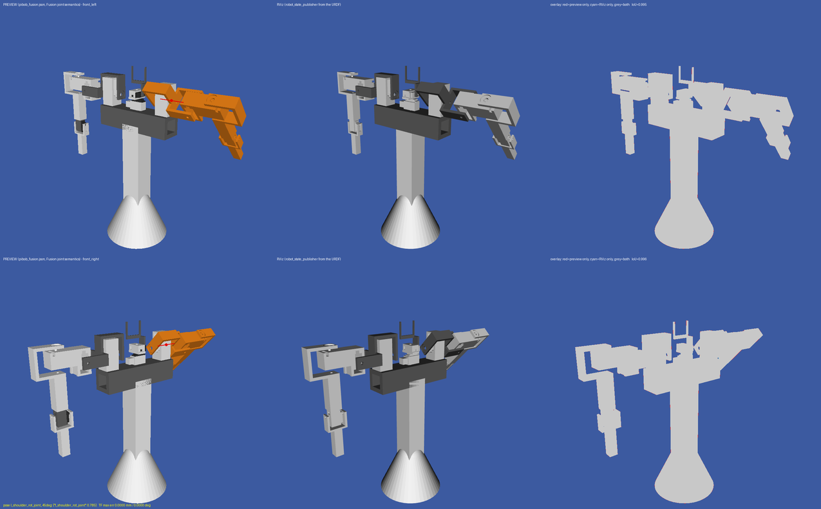
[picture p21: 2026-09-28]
fusion/verify/l_shoulder_rot_joint_45deg.png

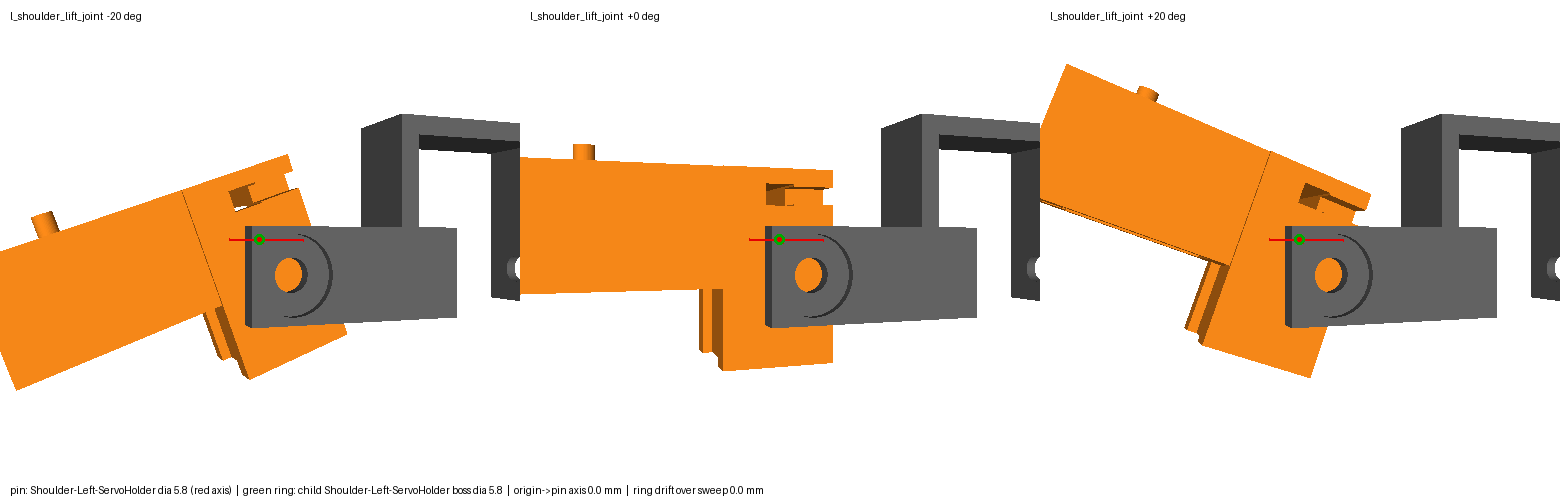
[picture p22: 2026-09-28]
fusion/verify/pins/l_shoulder_lift_joint.png

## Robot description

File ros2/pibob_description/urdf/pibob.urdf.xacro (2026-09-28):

<?xml version="1.0"?>
<robot name="pibob" xmlns:xacro="http://www.ros.org/wiki/xacro">

  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

  <xacro:property name="mesh_pkg" value="package://pibob_description/meshes"/>

  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
  <xacro:property name="show_top" value="true"/>
  <xacro:property name="show_bracket" value="true"/>
  <xacro:property name="show_holder" value="true"/>
  <xacro:property name="show_bicep" value="true"/>
  <xacro:property name="show_forearm" value="true"/>   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
  <xacro:property name="show_forearm_mesh" value="true"/>  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
  <xacro:macro name="servo_9g" params="xyz rpy">
    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
  </xacro:macro>

  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
  <link name="base_link">
    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
  </link>

  <joint name="base_to_beam" type="fixed">
    <parent link="base_link"/>
    <child link="shoulder_beam"/>
    <origin xyz="0 0 0.30" rpy="0 0 0"/>
  </joint>

  <link name="shoulder_beam">
    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
  </link>

  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
  <joint name="beam_to_head_base" type="fixed">
    <parent link="shoulder_beam"/>
    <child link="head_base_link"/>
    <origin xyz="0 0 0.0355" rpy="0 0 0"/>   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
  </joint>

  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
  <link name="head_base_link">
    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
    <xacro:servo_9g xyz="0 0 0.0267" rpy="0 0 ${pi/2}"/>    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
  </link>

  <joint name="head_pan_joint" type="revolute">
    <parent link="shoulder_beam"/>
    <child link="head_pan_link"/>
    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
    <origin xyz="0 0 0.0622" rpy="0 0 0"/>
    <axis xyz="0 0 1"/>
    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
    <limit lower="-1.5708" upper="1.5708" effort="1.0" velocity="3.14"/>
  </joint>

  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
  <link name="head_pan_link">
    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
    <xacro:servo_9g xyz="-0.00315 0.0172 0.01105" rpy="${-pi/2} 0 0"/>    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
  </link>

  <joint name="head_tilt_joint" type="revolute">
    <parent link="head_pan_link"/>
    <child link="head_tilt_link"/>
    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
    <origin xyz="-0.00315 0.0172 0.01105" rpy="0 0 0"/>
    <axis xyz="0 1 0"/>
    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
    <limit lower="-0.6981" upper="0.8727" effort="1.0" velocity="3.14"/>
  </joint>

  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
  <link name="head_tilt_link">
    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
  </link>

  <joint name="head_to_camera" type="fixed">
    <parent link="head_tilt_link"/>
    <child link="camera_link"/>
    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
    <origin xyz="-0.00625 -0.0195 0.04467" rpy="0 0 0"/>
  </joint>

  <link name="camera_link"/>

  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
  <xacro:macro name="arm" params="side reflect bracket_mesh holder_mesh">

    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
    <joint name="${side}_shoulder_top_joint" type="fixed">
      <parent link="shoulder_beam"/>
      <child link="${side}_shoulder_top_link"/>
      <origin xyz="0 ${0.085*reflect} 0.065" rpy="0 0 0"/>
    </joint>
    <link name="${side}_shoulder_top_link">
      <xacro:if value="${show_top}">
      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
      </xacro:if>
    </link>

    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
    <joint name="${side}_shoulder_rot_joint" type="revolute">
      <parent link="${side}_shoulder_top_link"/>
      <child link="${side}_shoulder_rot_link"/>
      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
      <origin xyz="0 ${0.01345*reflect} 0.0049" rpy="0 0 0"/>
      <axis xyz="0 ${reflect} 0"/>
      <limit lower="-0.3491" upper="1.0472" effort="1.0" velocity="3.14"/>
    </joint>
    <link name="${side}_shoulder_rot_link">
      <xacro:if value="${show_bracket}">
      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
      </xacro:if>
    </link>

    <joint name="${side}_shoulder_lift_joint" type="revolute">
      <parent link="${side}_shoulder_rot_link"/>
      <child link="${side}_shoulder_lift_link"/>
      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
      <origin xyz="-0.01345 ${0.05605*reflect} 0.00465" rpy="0 0 0"/>
      <axis xyz="${reflect} 0 0"/>   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
      <limit lower="-0.3491" upper="0.3491" effort="1.0" velocity="3.14"/>
    </joint>
    <link name="${side}_shoulder_lift_link">
      <xacro:if value="${show_holder}">
      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
      </xacro:if>
    </link>

    <joint name="${side}_arm_rot_joint" type="revolute">
      <parent link="${side}_shoulder_lift_link"/>
      <child link="${side}_upper_arm_link"/>
      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
      <origin xyz="0.017 ${0.0511*reflect} 0.0199" rpy="0 0 0"/>
      <axis xyz="0 0 1"/>
      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
      <limit lower="-0.9" upper="0.9" effort="1.0" velocity="3.14"/>
    </joint>
    <link name="${side}_upper_arm_link">
      <xacro:if value="${show_bicep}">
      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
      </xacro:if>
      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
      <xacro:if value="${show_forearm}">
      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
      <xacro:servo_9g xyz="0.00045 ${-0.0138*reflect} -0.13455" rpy="${pi/2} ${pi/2} ${(1-reflect)/2*pi}"/>
      </xacro:if>
    </link>

    <joint name="${side}_bicep_joint" type="revolute">
      <parent link="${side}_upper_arm_link"/>
      <child link="${side}_forearm_link"/>
      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
      <origin xyz="0.00045 ${0.0129*reflect} -0.13455" rpy="0 0 0"/>
      <axis xyz="0 -1 0"/>   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
      <limit lower="0.0" upper="1.5708" effort="1.0" velocity="3.14"/>
    </joint>
    <link name="${side}_forearm_link">
      <xacro:if value="${show_forearm_mesh}">
      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
      </xacro:if>
    </link>

  </xacro:macro>

  <xacro:arm side="r" reflect="-1" bracket_mesh="Shoulder-Right-Bracket.stl" holder_mesh="Shoulder-Right-ServoHolder.stl"/>
  <xacro:arm side="l" reflect="1" bracket_mesh="Shoulder-Left-Bracket.stl" holder_mesh="Shoulder-Left-ServoHolder.stl"/>

</robot>

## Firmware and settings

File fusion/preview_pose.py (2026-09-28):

#!/usr/bin/env python3
"""Pose + render PiBob using ONLY pibob_fusion.json - the same data the Fusion script uses.

    uv run --with numpy --with trimesh --with pillow fusion/preview_pose.py \
        --pose head_pan_joint=0.785 --view front_left --out /tmp/p.png
    uv run ... fusion/preview_pose.py --pivot-check

Motion semantics are exactly what a Fusion revolute joint does: for each revolute
joint (parents first) rotate the whole CHILD SUBTREE by the angle about the line
through the joint's CURRENT world pivot along its CURRENT world axis. Nothing here
reads the URDF, so agreement with RViz (robot_state_publisher) is a real check of
the JSON pivots/axes, not a restatement of them.

The renderer is a tiny z-buffered pinhole-camera rasteriser (numpy + Pillow),
using the same camera model as RViz's Orbit view (eye = focal + d*(cos p cos y,
cos p sin y, sin p), Z up, vertical FOV 45 deg), so preview and RViz screenshots can
be laid side by side and overlaid pixel-for-pixel.
"""
import argparse
import json
import math
import os

import numpy as np

HERE = os.path.dirname(os.path.abspath(__file__))
DEFAULT_JSON = os.path.join(HERE, "pibob_fusion.json")

# Named cameras shared with verify/run_verification.py (RViz Orbit parameters).
VIEWS = {
    "front_left":  dict(yaw=0.70, pitch=0.30, distance=0.75, focal=(0.0, 0.0, 0.29)),
    "front_right": dict(yaw=-0.70, pitch=0.30, distance=0.75, focal=(0.0, 0.0, 0.29)),
    "left_side":   dict(yaw=1.5708, pitch=0.15, distance=0.75, focal=(0.0, 0.0, 0.29)),
    # head close-ups (focal on the head, ~0.2 m away)
    "head_front":  dict(yaw=0.0, pitch=0.10, distance=0.24, focal=(0.0, 0.0, 0.378)),
    "head_side":   dict(yaw=1.5708, pitch=0.60, distance=0.24, focal=(0.0, 0.0, 0.378)),   # looks over the left shoulder
    "head_3q":     dict(yaw=0.75, pitch=0.35, distance=0.24, focal=(0.0, 0.0, 0.378)),
    "head_3q_back": dict(yaw=2.4, pitch=0.35, distance=0.24, focal=(0.0, 0.0, 0.378)),
    # tighter, level close-ups for the head-only sheet (verify/head_closeup.png)
    "close_front": dict(yaw=0.0, pitch=0.05, distance=0.17, focal=(0.0, 0.0, 0.385)),
    "close_left":  dict(yaw=1.5708, pitch=0.05, distance=0.17, focal=(0.0, 0.0, 0.385)),
    "close_3q":    dict(yaw=0.75, pitch=0.30, distance=0.17, focal=(0.0, 0.0, 0.380)),
    "close_3q_back": dict(yaw=2.4, pitch=0.30, distance=0.17, focal=(0.0, 0.0, 0.380)),
}
FOVY = math.pi / 4          # RViz/Ogre default camera vertical field of view
HEAD_LINKS = ("shoulder_beam", "head_base_link", "head_pan_link", "head_tilt_link", "camera_link")


# ---------------------------------------------------------------- data
def load(json_path=DEFAULT_JSON):
    with open(json_path) as f:
        data = json.load(f)
    data["_dir"] = os.path.dirname(os.path.abspath(json_path))
    return data


_MESH_CACHE = {}


def load_mesh(data, visual):
    """STL -> (vertices Nx3 in METRES in the link frame, faces Mx3)."""
    import trimesh
    path = os.path.join(data["_dir"], visual["stl"])
    if path not in _MESH_CACHE:
        m = trimesh.load(path, force="mesh", process=False)
        _MESH_CACHE[path] = (np.asarray(m.vertices, float), np.asarray(m.faces, int))
    v, f = _MESH_CACHE[path]
    v = v * np.asarray(visual["scale"])
    T = np.asarray(visual["origin"])
    return (T[:3, :3] @ v.T).T + T[:3, 3], f


# ---------------------------------------------------------------- kinematics
def axis_angle(axis, ang):
    a = np.asarray(axis, float)
    a = a / np.linalg.norm(a)
    K = np.array([[0, -a[2], a[1]], [a[2], 0, -a[0]], [-a[1], a[0], 0]])
    return np.eye(3) + math.sin(ang) * K + (1 - math.cos(ang)) * K @ K


def rot_about_line(point, axis, ang):
    """4x4 world transform: rotate by ang about the line (point, axis)."""
    R = axis_angle(axis, ang)
    p = np.asarray(point, float)
    T = np.eye(4)
    T[:3, :3] = R
    T[:3, 3] = p - R @ p
    return T


def subtree(data, link):
    kids = {}
    for j in data["joints"]:
        kids.setdefault(j["parent"], []).append(j["child"])
    out, stack = [], [link]
    while stack:
        n = stack.pop()
        out.append(n)
        stack.extend(kids.get(n, []))
    return out


def pose_world(data, angles):
    """{link: posed 4x4 world transform}. angles = {joint_name: rad} (missing = 0)."""
    W0 = {l["name"]: np.asarray(l["world"], float) for l in data["links"]}
    W = {k: v.copy() for k, v in W0.items()}
    for j in data["joints"]:                        # JSON order = parents first
        ang = float(angles.get(j["name"], 0.0))
        if j["type"] == "fixed" or ang == 0.0:
            continue
        # The joint's pivot/axis move with everything upstream of it: carry the
        # zero-pose world pivot/axis through the parent link's accumulated motion.
        D = W[j["parent"]] @ np.linalg.inv(W0[j["parent"]])
        pivot = D[:3, :3] @ np.asarray(j["origin_world"]) + D[:3, 3]
        axis = D[:3, :3] @ np.asarray(j["axis_world"])
        R = rot_about_line(pivot, axis, ang)
        for n in subtree(data, j["child"]):
            W[n] = R @ W[n]
    return W


def posed_meshes(data, W, links=None):
    """[(link, verts_world, faces, rgba)] at the posed transforms (optionally only `links`)."""
    out = []
    for l in data["links"]:
        if links is not None and l["name"] not in links:
            continue
        for vis in l["visuals"]:
            v, f = load_mesh(data, vis)
            T = W[l["name"]]
            out.append((l["name"], (T[:3, :3] @ v.T).T + T[:3, 3], f, vis.get("rgba") or [0.8, 0.8, 0.8, 1]))
    return out


# ---------------------------------------------------------------- render
def camera(view):
    y, p, d = view["yaw"], view["pitch"], view["distance"]
    f = np.asarray(view["focal"], float)
    eye = f + d * np.array([math.cos(p) * math.cos(y), math.cos(p) * math.sin(y), math.sin(p)])
    fwd = (f - eye) / np.linalg.norm(f - eye)
    right = np.cross(fwd, [0, 0, 1.0])
    right /= np.linalg.norm(right)
    up = np.cross(right, fwd)
    return eye, fwd, right, up


def project(pts, view, w, h):
    eye, fwd, right, up = camera(view)
    v = pts - eye
    zc = v @ fwd
    k = (h / 2) / math.tan(FOVY / 2)
    sx = w / 2 + k * (v @ right) / zc
    sy = h / 2 - k * (v @ up) / zc
    return np.stack([sx, sy], 1), zc


def _rasterise(img, zbuf, s, z, cols):
    """Z-buffered flat-shaded triangle fill. s: Mx3x2 screen pts, z: Mx3 depths, cols: Mx3 (0..1)."""
    h, w = zbuf.shape
    for t in range(len(s)):
        (x0, y0), (x1, y1), (x2, y2) = s[t]
        if min(z[t]) <= 0:
            continue
        xa, xb = max(int(math.floor(min(x0, x1, x2))), 0), min(int(math.ceil(max(x0, x1, x2))), w - 1)
        ya, yb = max(int(math.floor(min(y0, y1, y2))), 0), min(int(math.ceil(max(y0, y1, y2))), h - 1)
        if xa > xb or ya > yb:
            continue
        den = (y1 - y2) * (x0 - x2) + (x2 - x1) * (y0 - y2)
        if abs(den) < 1e-12:
            continue
        X, Y = np.meshgrid(np.arange(xa, xb + 1) + 0.5, np.arange(ya, yb + 1) + 0.5)
        l0 = ((y1 - y2) * (X - x2) + (x2 - x1) * (Y - y2)) / den
        l1 = ((y2 - y0) * (X - x2) + (x0 - x2) * (Y - y2)) / den
        l2 = 1 - l0 - l1
        inside = (l0 >= -1e-9) & (l1 >= -1e-9) & (l2 >= -1e-9)
        if not inside.any():
            continue
        # perspective-correct depth: interpolate 1/z
        zz = 1.0 / (l0 / z[t][0] + l1 / z[t][1] + l2 / z[t][2])
        sub = zbuf[ya:yb + 1, xa:xb + 1]
        win = inside & (zz < sub)
        sub[win] = zz[win]
        img[ya:yb + 1, xa:xb + 1][win] = cols[t]


def render(data, W, view, w=850, h=790, highlight=(), pivots=(), out=None, title=None,
           grid=True, bg=(1, 1, 1), links=None, marks=()):
    """Render posed meshes (z-buffered). highlight = links tinted orange; pivots = [(point, axis)] in red.
    Returns an HxWx3 uint8 image (and saves it to `out` if given)."""
    from PIL import Image, ImageDraw

    eye, fwd, _, _ = camera(view)
    img = np.zeros((h, w, 3), float) + np.asarray(bg, float)
    zbuf = np.full((h, w), np.inf)

    if grid:  # RViz default grid: 10 x 10 cells of 0.1 m on z=0, centred at origin (drawn under the model)
        g = Image.fromarray((img * 255).astype(np.uint8))
        d = ImageDraw.Draw(g)
        for i in range(11):
            c = -0.5 + i * 0.1
            for a, b in (([c, -0.5, 0], [c, 0.5, 0]), ([-0.5, c, 0], [0.5, c, 0])):
                sp, _ = project(np.array([a, b], float), view, w, h)
                d.line([tuple(sp[0]), tuple(sp[1])], fill=(180, 180, 180), width=1)
        img = np.asarray(g, float) / 255.0

    for link, v, f, rgba in posed_meshes(data, W, links):
        tri = v[f]                                           # M x 3 x 3
        n = np.cross(tri[:, 1] - tri[:, 0], tri[:, 2] - tri[:, 0])
        n /= np.linalg.norm(n, axis=1, keepdims=True) + 1e-12
        shade = 0.35 + 0.65 * np.abs(n @ -fwd)
        base = np.array([1.0, 0.55, 0.1]) if link in highlight else np.array(rgba[:3])
        sp, z = project(tri.reshape(-1, 3), view, w, h)
        _rasterise(img, zbuf, sp.reshape(-1, 3, 2), z.reshape(-1, 3),
                   np.clip(base[None, :] * shade[:, None], 0, 1))

    im = Image.fromarray((np.clip(img, 0, 1) * 255).astype(np.uint8))
    d = ImageDraw.Draw(im)
    for p, a in pivots:  # pivot dot + 60 mm axis line through it (drawn on top)
        a = np.asarray(a) / np.linalg.norm(a)
        sp, _ = project(np.array([p - 0.03 * a, p + 0.03 * a, p]), view, w, h)
        d.line([tuple(sp[0]), tuple(sp[1])], fill=(230, 0, 0), width=3)
        x, y = sp[2]
        d.ellipse([x - 4, y - 4, x + 4, y + 4], fill=(230, 0, 0))
    for p, col in marks:  # extra coloured dots (e.g. a hole centre)
        sp, _ = project(np.asarray([p], float), view, w, h)
        x, y = sp[0]
        d.ellipse([x - 5, y - 5, x + 5, y + 5], outline=col, width=3)
    if title:
        d.text((10, 10), title, fill=(0, 0, 0) if sum(bg) > 1.5 else (255, 255, 255))
    if out:
        im.save(out)
    return np.asarray(im)


# ---------------------------------------------------------------- pivot sanity check
def _point_tri_dist(p, tri):
    """Distance from p to each triangle (M x 3 x 3), vectorised (Ericson, closest point)."""
    a, b, c = tri[:, 0], tri[:, 1], tri[:, 2]
    ab, ac, ap = b - a, c - a, p - a
    d1, d2 = (ab * ap).sum(1), (ac * ap).sum(1)
    bp = p - b
    d3, d4 = (ab * bp).sum(1), (ac * bp).sum(1)
    cp = p - c
    d5, d6 = (ab * cp).sum(1), (ac * cp).sum(1)
    va = d3 * d6 - d5 * d4
    vb = d5 * d2 - d1 * d6
    vc = d1 * d4 - d3 * d2
    denom = va + vb + vc
    denom[denom == 0] = 1e-18
    v, w = vb / denom, vc / denom
    closest = a + ab * v[:, None] + ac * w[:, None]
    # region tests (vertex / edge regions)
    m = (d1 <= 0) & (d2 <= 0); closest[m] = a[m]
    m = (d3 >= 0) & (d4 <= d3); closest[m] = b[m]
    m = (d6 >= 0) & (d5 <= d6); closest[m] = c[m]
    m = (vc <= 0) & (d1 >= 0) & (d3 <= 0)
    t = d1 / np.where(d1 - d3 == 0, 1e-18, d1 - d3); closest[m] = (a + ab * t[:, None])[m]
    m = (vb <= 0) & (d2 >= 0) & (d6 <= 0)
    t = d2 / np.where(d2 - d6 == 0, 1e-18, d2 - d6); closest[m] = (a + ac * t[:, None])[m]
    m = (va <= 0) & ((d4 - d3) >= 0) & ((d5 - d6) >= 0)
    t = (d4 - d3) / np.where((d4 - d3) + (d5 - d6) == 0, 1e-18, (d4 - d3) + (d5 - d6))
    closest[m] = (b + (c - b) * t[:, None])[m]
    return np.linalg.norm(p - closest, axis=1)


def _inside(p, tri):
    """Ray-parity point-in-mesh test (+X ray; ok for closed printable STLs)."""
    d = np.array([1.0, 0.1234, 0.0567]); d /= np.linalg.norm(d)
    e1, e2 = tri[:, 1] - tri[:, 0], tri[:, 2] - tri[:, 0]
    h = np.cross(d, e2)
    a = (e1 * h).sum(1)
    ok = np.abs(a) > 1e-15
    f = np.where(ok, 1 / np.where(ok, a, 1), 0)
    s = p - tri[:, 0]
    u = f * (s * h).sum(1)
    q = np.cross(s, e1)
    v = f * (q @ d)
    t = f * (e2 * q).sum(1)
    hits = ok & (u >= 0) & (u <= 1) & (v >= 0) & (u + v <= 1) & (t > 1e-12)
    return bool(hits.sum() % 2)


def pivot_check(data):
    """For each revolute joint: distance (mm) from the pivot to the parent- and child-link meshes."""
    W = pose_world(data, {})
    meshes = {}
    for link, v, f, _ in posed_meshes(data, W):
        meshes.setdefault(link, []).append(v[f])
    # A joint's "parent side" is every link rigidly attached to its parent (fixed joints),
    # e.g. head_pan's servo lives in head_base_link, fixed to shoulder_beam.
    adj = {}
    for fj in data["joints"]:
        if fj["type"] == "fixed":
            adj.setdefault(fj["parent"], []).append(fj["child"])
            adj.setdefault(fj["child"], []).append(fj["parent"])

    def rigid_group(link):
        seen, stack = {link}, [link]
        while stack:
            for n in adj.get(stack.pop(), []):
                if n not in seen:
                    seen.add(n)
                    stack.append(n)
        return seen

    rows = []
    for j in data["joints"]:
        if j["type"] == "fixed":
            continue
        p = np.asarray(j["origin_world"])
        row = {"joint": j["name"]}
        for side in ("parent", "child"):
            group = [m for n in rigid_group(j[side]) for m in meshes.get(n, [])]
            tris = np.concatenate(group or [np.zeros((0, 3, 3))])
            if len(tris) == 0:
                row[side] = None
                continue
            dist = float(_point_tri_dist(p, tris).min()) * 1000
            ins = any(_inside(p, t) for t in group)
            lo, hi = tris.reshape(-1, 3).min(0), tris.reshape(-1, 3).max(0)
            # how far outside the part's axis-aligned envelope (0 = within it, e.g. in the servo pocket)
            out_bb = float(np.linalg.norm(np.maximum(0, np.maximum(lo - p, p - hi)))) * 1000
            row[side] = {"link": j[side], "surface_mm": round(dist, 2), "inside_material": ins,
                         "outside_envelope_mm": round(out_bb, 2)}
        rows.append(row)
    return rows


# ---------------------------------------------------------------- servo + contact checks
SERVO_TAG = "Servo-9g"
# Parts that should physically touch, as (link, part, link, part). Gaps are reported.
HEAD_CONTACTS = [
    ("shoulder_beam", "Shoulder-Beam", "head_base_link", "Head-BottomServoHolder"),
    ("head_base_link", "Head-BottomServoHolder", "head_base_link", SERVO_TAG),
    ("head_base_link", SERVO_TAG, "head_pan_link", "Head-MiddleServoHolder"),
    ("head_pan_link", "Head-MiddleServoHolder", "head_pan_link", SERVO_TAG),
    ("head_pan_link", SERVO_TAG, "head_tilt_link", "Head-CameraHolder"),
]


def _visual_world(data, W):
    """[(link, part name, 4x4 world of the visual frame, tris)]"""
    out = []
    for l in data["links"]:
        for vis in l["visuals"]:
            v, f = load_mesh(data, vis)
            T = W[l["name"]]
            part = os.path.splitext(os.path.basename(vis["stl"]))[0]
            out.append((l["name"], part, T @ np.asarray(vis["origin"]),
                        ((T[:3, :3] @ v.T).T + T[:3, 3])[f]))
    return out


def servo_check(data):
    """For each revolute joint, the 9 g servo whose output shaft it should sit on:
    distance pivot->shaft axis (mm), pivot offset along the shaft from the servo's top
    face (mm, + = out of the servo), and angle between shaft and joint axis (deg)."""
    vw = _visual_world(data, pose_world(data, {}))
    servos = [(l, T) for l, part, T, _ in vw if part == SERVO_TAG]
    rows = []
    for j in data["joints"]:
        if j["type"] == "fixed":
            continue
        p, a = np.asarray(j["origin_world"]), np.asarray(j["axis_world"])
        best = None
        for link, T in servos:
            o, z = T[:3, 3], T[:3, 2]
            ang = math.degrees(math.acos(min(1.0, abs(float(z @ a)))))
            d = p - o
            radial = float(np.linalg.norm(d - (d @ z) * z)) * 1000
            key = (round(ang, 3), round(radial, 3), abs(float(d @ z)))
            if best is None or key < best["_key"]:
                best = {"servo_in": link, "radial_mm": round(radial, 3),
                        "axial_mm": round(float(d @ z) * 1000, 3), "angle_deg": round(ang, 3), "_key": key}
        if best and best["angle_deg"] < 1 and best["radial_mm"] < 1:
            best.pop("_key")
            rows.append({"joint": j["name"], **best})
        else:
            rows.append({"joint": j["name"], "servo_in": None})
    return rows


def _mesh_gap(ta, tb):
    """Min distance (mm) between two triangle soups, sampled at vertices/centroids/edge midpoints."""
    def samples(t):
        return np.concatenate([t.reshape(-1, 3), t.mean(1), (t[:, 0] + t[:, 1]) / 2,
                               (t[:, 1] + t[:, 2]) / 2, (t[:, 2] + t[:, 0]) / 2])
    best = np.inf
    for s, t in ((samples(ta), tb), (samples(tb), ta)):
        s = np.unique(s.round(7), axis=0)
        lo, hi = t.reshape(-1, 3).min(0) - 0.01, t.reshape(-1, 3).max(0) + 0.01
        near = s[np.all((s > lo) & (s < hi), axis=1)] if best > 0.01 else s
        for q in (near if len(near) else s[:200]):
            best = min(best, float(_point_tri_dist(q, t).min()))
    return best * 1000


def contact_check(data, pairs=HEAD_CONTACTS):
    vw = _visual_world(data, pose_world(data, {}))
    get = {}
    for link, part, _, tris in vw:
        get.setdefault((link, part), []).append(tris)
    rows = []
    for la, pa, lb, pb in pairs:
        ta, tb = get.get((la, pa)), get.get((lb, pb))
        if not ta or not tb:
            rows.append({"a": f"{la}/{pa}", "b": f"{lb}/{pb}", "gap_mm": None})
            continue
        rows.append({"a": f"{la}/{pa}", "b": f"{lb}/{pb}",
                     "gap_mm": round(min(_mesh_gap(x, y) for x in ta for y in tb), 3)})
    return rows


# ---------------------------------------------------------------- CLI
def main():
    ap = argparse.ArgumentParser(description=__doc__, formatter_class=argparse.RawDescriptionHelpFormatter)
    ap.add_argument("--json", default=DEFAULT_JSON)
    ap.add_argument("--pose", nargs="*", default=[], help="joint=radians ...")
    ap.add_argument("--view", default="front_left", choices=sorted(VIEWS))
    ap.add_argument("--out", default="preview.png")
    ap.add_argument("--pivot-check", action="store_true")
    ap.add_argument("--head-only", action="store_true", help="render only the beam + head links")
    ap.add_argument("--servo-check", action="store_true", help="each joint pivot vs its servo's shaft")
    ap.add_argument("--contact-check", action="store_true", help="gaps between head parts that should touch")
    a = ap.parse_args()
    data = load(a.json)
    if a.pivot_check:
        for r in pivot_check(data):
            def fmt(s):
                return "-" if s is None else (f"{s['link']:21s} surf {s['surface_mm']:5.1f}mm "
                                              f"env+{s['outside_envelope_mm']:4.1f}mm")
            print(f"{r['joint']:24s} parent: {fmt(r['parent'])} | child: {fmt(r['child'])}")
        return
    if a.servo_check:
        for r in servo_check(data):
            if r["servo_in"] is None:
                print(f"{r['joint']:24s} no 9 g servo on this axis (DS3218 arm joints are not modelled)")
            else:
                print(f"{r['joint']:24s} servo in {r['servo_in']:18s} off-axis {r['radial_mm']:.3f} mm, "
                      f"{r['axial_mm']:+.3f} mm from its top face, axis angle {r['angle_deg']:.3f} deg")
        return
    if a.contact_check:
        for r in contact_check(data):
            print(f"{r['a']:42s} <-> {r['b']:42s} gap {r['gap_mm']} mm")
        return
    angles = {k: float(v) for k, v in (p.split("=") for p in a.pose)}
    W = pose_world(data, angles)
    render(data, W, VIEWS[a.view], out=a.out, title=" ".join(a.pose) or "zero pose",
           links=HEAD_LINKS if a.head_only else None, grid=not a.head_only)
    print("wrote", a.out)


if __name__ == "__main__":
    main()

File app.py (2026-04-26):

#!/usr/bin/env python3
import json
import os
import time
import threading
from flask import Flask, render_template_string, request, jsonify, Response
from adafruit_servokit import ServoKit
import cv2

kit = ServoKit(channels=16)

# Webcam setup
camera = cv2.VideoCapture(0)
if camera.isOpened():
    camera.set(cv2.CAP_PROP_FRAME_WIDTH, 640)
    camera.set(cv2.CAP_PROP_FRAME_HEIGHT, 480)
else:
    print("Warning: No camera detected. Video feed will be unavailable.")
camera_lock = threading.Lock()

BASE_DIR = os.path.dirname(os.path.abspath(__file__))
PRESETS_FILE = os.path.join(BASE_DIR, "presets.json")
CONFIG_FILE = os.path.join(BASE_DIR, "config.json")

# Joint names and default safe limits for robot channels
CHANNEL_DEFAULTS = {
    2:  {"name": "Head Rotation",    "safe_min": 0,   "safe_max": 180, "reversed": False},
    3:  {"name": "Head Tilt",        "safe_min": 50,  "safe_max": 140, "reversed": False},
    4:  {"name": "R Bicep",          "safe_min": 90,  "safe_max": 180, "reversed": False},
    5:  {"name": "R Arm Rotation",   "safe_min": 70,  "safe_max": 110, "reversed": True},
    6:  {"name": "R Shoulder Lift",  "safe_min": 70,  "safe_max": 110, "reversed": True},
    7:  {"name": "R Shoulder Rot",   "safe_min": 70,  "safe_max": 150, "reversed": True},
    8:  {"name": "L Bicep",          "safe_min": 90,  "safe_max": 180, "reversed": True},
    9:  {"name": "L Arm Rotation",   "safe_min": 70,  "safe_max": 110, "reversed": False},
    10: {"name": "L Shoulder Lift",  "safe_min": 70,  "safe_max": 110, "reversed": False},
    11: {"name": "L Shoulder Rot",   "safe_min": 70,  "safe_max": 150, "reversed": False},
}


def load_config():
    if os.path.exists(CONFIG_FILE):
        with open(CONFIG_FILE) as f:
            return json.load(f)
    return {}


def save_config(config):
    with open(CONFIG_FILE, "w") as f:
        json.dump(config, f, indent=2)


# Channel state: mode (servo/continuous/pwm), value, enabled, pulse range
saved_config = load_config()
channels = {}
for i in range(16):
    defaults = CHANNEL_DEFAULTS.get(i, {})
    saved = saved_config.get(str(i), {})
    channels[i] = {
        "mode": "servo",
        "value": 90,
        "enabled": True,
        "reversed": defaults.get("reversed", False),
        "min_pulse": 400,
        "max_pulse": 2600,
        "name": saved.get("name", defaults.get("name", "")),
        "safe_min": saved.get("safe_min", defaults.get("safe_min", 0)),
        "safe_max": saved.get("safe_max", defaults.get("safe_max", 180)),
    }
    try:
        kit.servo[i].set_pulse_width_range(400, 2600)
        kit.servo[i].angle = 90
    except Exception:
        pass

pwm_frequency = 50


def load_presets():
    if os.path.exists(PRESETS_FILE):
        with open(PRESETS_FILE) as f:
            return json.load(f)
    return {}


def save_presets(presets):
    with open(PRESETS_FILE, "w") as f:
        json.dump(presets, f, indent=2)


def apply_reverse(ch, angle):
    """If channel is reversed, flip the angle (180 - angle)."""
    if channels[ch].get("reversed", False):
        return 180 - angle
    return angle


app = Flask(__name__)

HTML = r"""<!DOCTYPE html>
<html lang="en">
<head>
<meta charset="UTF-8">
<meta name="viewport" content="width=device-width, initial-scale=1.0">
<title>PiBob Servo Control</title>
<style>
  * { box-sizing: border-box; margin: 0; padding: 0; }
  body { font-family: -apple-system, BlinkMacSystemFont, 'Segoe UI', sans-serif; background: #1a1a2e; color: #eee; padding: 16px; }
  h1 { text-align: center; margin-bottom: 16px; color: #e94560; font-size: 22px; }

  .top-bar { max-width: 1200px; margin: 0 auto 16px; display: flex; flex-wrap: wrap; gap: 12px; align-items: center; justify-content: center; }
  .top-section { background: #16213e; border-radius: 10px; padding: 12px 16px; border: 1px solid #0f3460; display: flex; align-items: center; gap: 8px; flex-wrap: wrap; }
  .top-section label { font-size: 12px; color: #888; font-weight: bold; text-transform: uppercase; }
  .top-section input, .top-section select { background: #0f3460; border: 1px solid #1a3a6e; color: #fff; padding: 6px 10px; border-radius: 6px; font-size: 13px; }
  .top-section input[type=number] { width: 70px; }

  .btn { padding: 7px 14px; border: none; border-radius: 6px; cursor: pointer; font-size: 12px; font-weight: bold; background: #e94560; color: #fff; }
  .btn:hover { background: #c73e54; }
  .btn:active { opacity: 0.7; }
  .btn-sm { padding: 5px 10px; font-size: 11px; }
  .btn-outline { background: transparent; border: 1px solid #e94560; color: #e94560; }
  .btn-outline:hover { background: #e94560; color: #fff; }
  .btn-blue { background: #0f3460; color: #eee; }
  .btn-blue:hover { background: #1a4a80; }
  .btn-green { background: #1b9e4b; }
  .btn-green:hover { background: #178a42; }
  .btn-danger { background: #a01030; }
  .btn-danger:hover { background: #c01040; }

  .grid { display: grid; grid-template-columns: repeat(4, 1fr); gap: 12px; max-width: 1400px; margin: 0 auto; }
  .card { background: #16213e; border-radius: 10px; padding: 14px; border: 1px solid #0f3460; transition: opacity 0.2s; }
  .card.disabled { opacity: 0.4; }
  .card-header { display: flex; justify-content: space-between; align-items: center; margin-bottom: 10px; }
  .card-header h3 { color: #e94560; font-size: 13px; }
  .card-header .controls { display: flex; gap: 6px; align-items: center; }

  .mode-select { background: #0f3460; border: 1px solid #1a3a6e; color: #fff; padding: 4px 8px; border-radius: 6px; font-size: 11px; }
  .toggle { position: relative; width: 36px; height: 20px; cursor: pointer; }
  .toggle input { display: none; }
  .toggle span { position: absolute; inset: 0; background: #555; border-radius: 10px; transition: 0.2s; }
  .toggle input:checked + span { background: #1b9e4b; }
  .toggle span::after { content: ''; position: absolute; left: 2px; top: 2px; width: 16px; height: 16px; background: #fff; border-radius: 50%; transition: 0.2s; }
  .toggle input:checked + span::after { left: 18px; }

  .slider-row { display: flex; align-items: center; gap: 8px; margin-bottom: 6px; }
  input[type=range] { flex: 1; accent-color: #e94560; height: 6px; }
  .val { font-size: 18px; font-weight: bold; min-width: 50px; text-align: right; color: #fff; }
  .unit { font-size: 11px; color: #888; margin-left: 2px; }

  .btn-row { display: flex; gap: 4px; margin-bottom: 6px; }
  .btn-row button { flex: 1; }

  .rev-row { display: flex; align-items: center; gap: 6px; margin-bottom: 6px; font-size: 11px; color: #888; }
  .rev-row span { font-weight: bold; }
  .pulse-row { display: flex; align-items: center; gap: 6px; font-size: 11px; color: #888; }
  .pulse-row input { width: 60px; background: #0f3460; border: 1px solid #1a3a6e; color: #fff; padding: 3px 6px; border-radius: 4px; font-size: 11px; text-align: center; }
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

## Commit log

2026-03-10 Added camera feed
2026-04-26 Prepare for open source release (v0.1)
    - Add MIT license, requirements.txt, and assembly guide with photos
    - Fix hardcoded paths to use script directory instead of /home/burf2000
    - Add camera fallback when no camera is detected
    - Change default port to 8080 (configurable via PORT env var)
    - Switch to opencv-python-headless for Raspberry Pi compatibility
    - Expand .gitignore for Python projects
    - Add STL files and build images
    - Rewrite README with WIP notice, BOM links, and step-by-step assembly
    [Arm-Bicep.stl, Arm-Elbow.stl, Arm-Forearm.stl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]
2026-05-05 Add ROS 2 URDF and servo bridge driver
    - pibob_description: xacro URDF with STL meshes, RViz display launch.
    - pibob_driver: Python node bridging /joint_commands JointState to the
    existing Flask /set endpoint, with per-joint channel/sign/limits in
    config/joint_map.yaml.
    Untested on a ROS 2 install; link offsets and joint axes will likely
    need calibration against the physical robot.
    [Arm-Bicep.stl, Arm-Elbow.stl, Arm-Forearm.stl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]
2026-06-05 Dockerised ROS2 Humble + RViz (browser via noVNC), optional real-robot control
    Run the PiBob stack on a Mac with just Docker — no local ROS install — and see
    the robot in RViz in a browser, move the joint sliders, and optionally drive
    the real PiBob with the same sliders.
    - ros2/docker/: Dockerfile (FROM ros:humble — arm64-native so RViz runs at
    full speed on Apple Silicon; the osrf desktop image is amd64-only/emulated),
    noVNC entrypoint (Xvfb + openbox + x11vnc + websockify → http://localhost:6080),
    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
2026-06-05 Fix URDF mesh orientations and robot_description launch param
    Add rpy origins to align servo holder, arm, and camera meshes, adjust
    joint origins, and wrap robot_description Command in ParameterValue so
    it is published as a string.
    [Arm-Bicep.stl, Arm-Elbow.stl, Arm-Forearm.stl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]
2026-06-05 Add backup of original mesh STLs
    [Arm-Bicep.stl, Arm-Elbow.stl, Arm-Forearm.stl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]
2026-06-05 RViz: disable the oversized TF display by default
    The TF display had no Marker Scale, so it drew 1 m frame axes that swamped
    the ~0.5 m robot and hid the model. Default it off (and set Marker Scale 0.12
    for when it's re-enabled) so the RobotModel is clearly visible on load.
2026-06-05 Docker: live-edit hot-reload for the URDF + in-progress model tweaks
    Dev workflow so the URDF can be tuned without rebuilds:
    - entrypoint: a file-watcher (WATCH=1) that re-runs xacro and bounces the
    launch whenever pibob.urdf.xacro changes; RViz redraws in ~12s. Nodes are
    hard-killed by name between reloads so windows don't pile up; xacro errors
    are logged and the last good model kept.
    - dev.sh: one-command launcher that mounts the urdf/ dir and sets WATCH=1.
    - README: live-edit section.
    This beats native Mac URDF viewers because the container already has ROS +
    xacro + the package, so package:// meshes and the xacro macro resolve.
    Model tweaks so far (still being tuned via live-edit):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
    [pibob.urdf.xacro]
2026-06-09 urdf: fix arm mesh chain to match README assembly order
    Top-ServoHolder now FIXED to the beam (was mis-placed on shoulder_rot); bracket and
    L/R ServoHolder were swapped. Correct chain: beam -> Top(fixed) -> [CH7]bracket ->
    [CH6]L/R holder -> [CH5]bicep -> [CH4]elbow/forearm. Verified renders cleanly (RobotModel Ok).
    [pibob.urdf.xacro]
2026-06-09 urdf: per-part show flags (show_top/bracket/holder/bicep/forearm) to seat arm meshes one at a time
    [pibob.urdf.xacro]
2026-06-10 urdf: seat arm meshes (top/bracket/holder/bicep) with per-side mirroring
    - Correct chain per README: beam -> Top-ServoHolder(fixed) -> bracket -> L/R holder -> bicep.
    - Per-side reflect for Y offsets + 180/90 yaw inverts where meshes mirror.
    - Gimbal-lock at +/-90 pitch on the holder: baked 180 into Shoulder-Left-ServoHolder.stl
    (orig kept locally as .orig); bicep is a single mesh so left mirrored via 180 rotation.
    - Debug show_* toggles to seat one part at a time; forearm still to do.
    [Shoulder-Left-ServoHolder.stl, pibob.urdf.xacro]
2026-06-10 gitignore local *.stl.orig mesh backups
2026-06-10 urdf: split elbow onto bicep link; forearm swings with joint; mirror + axis fixes
    - Arm-Elbow now fixed on upper_arm_link (houses CH4 servo, stays put); Arm-Forearm on
    forearm_link swings with the elbow joint.
    - Elbow (bicep_joint) axis flipped so the elbow bends forward.
    - Forearm/elbow Y offsets use *reflect; per-side yaw mirrors the single-mesh parts.
    - show_forearm (elbow) / show_forearm_mesh (forearm) toggles for seating each.
    [pibob.urdf.xacro]
2026-06-10 urdf: shoulder-lift pivot knobs (lift_pivot_in/up) — move pivot to the connector without moving the arm
    Joint origin moves to the rotation point; holder visual + arm_rot origin auto-compensate
    so the arm stays put. Negative lift_pivot_in = outward toward the connector.
    [pibob.urdf.xacro]
2026-06-10 urdf: widen arm_rot range to +/-0.9rad (~51deg) from +/-20deg
    [pibob.urdf.xacro]
2026-06-11 fix(driver): auto-declare param overrides so servo_bridge actually loads joints
    Without automatically_declare_parameters_from_overrides=True the nested joints.* params
    from joint_map.yaml were never declared, so get_parameters_by_prefix('joints') returned
    empty and the bridge logged 'No joints configured' -> POSTed nothing. Now loads all 10.
    Found by first end-to-end hardware test (Bridging 10 joints to PiBob, /set HTTP 200).
2026-06-11 driver: flip sign for head_tilt + r_arm_rot (moved opposite on real robot)
    Verified against the physical PiBob via the servo_bridge hardware test.
2026-06-11 driver: flip l_shoulder_rot sign (verified opposite on hardware)
2026-06-11 cleanup: remove dead bringup.launch.py, document verified servo signs, fix stale URDF comments
    - delete legacy bringup.launch.py (broken — missing the ParameterValue/on_stderr
    fixes; superseded by pibob_bringup.launch.py).
    - joint_map.yaml: document the 3 hardware-verified sign flips (head_tilt/r_arm_rot/l_shoulder_rot).
    - urdf: correct stale comments (forearm per-side yaw, debug-toggle note). Kept the
    show_* toggles (default-on, documented) as a part-seating aid.
    [pibob.urdf.xacro]
2026-09-28 fusion: URDF -> Fusion 360 assembly generator, verified against RViz
    - urdf_to_fusion_data.py: expands the xacro, writes pibob_fusion.json (link world
    transforms, per-visual STL + origin, joint pivots/axes/limits).
    - PiBobAssembly/: Fusion script. One component per link at its URDF frame, one
    sub-component per visual (STL mesh in a base feature, native part frame),
    as-built revolute joints about the URDF axis through the URDF pivot with URDF
    limits, rigid for fixed, base grounded. Joints reference only link-component
    construction geometry so part bodies can be swapped. Post-build self-check
    drives each joint and fixes the sign convention if needed.
    - preview_pose.py + verify/: JS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
    [preview_pose.py]
2026-09-28 fusion: fix wrong joint axes + snap-back found in real Fusion
    - Revolute joints are now built from an explicit construction sketch line in the
    child link (origin -> along the URDF axis, sign included) via
    JointGeometry.createByCurve(line, StartKeyPoint) + ZAxisJointDirection.
    CustomJointDirection with a construction-axis proxy was ignored by Fusion
    (elbow/shoulder turned about vertical).
    - If the self-check still sees a wrong axis, the joint is rebuilt as
    createByPoint(origin) + X/Y/ZAxisJointDirection; the passing strategy is reported.
    - Self-check now measures the real rotation axis/angle/pivot drift from
    transform2 before/after and flags > 5 deg; says NO UPDATE if the API does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
2026-09-28 head: seat the head on modelled 9 g servos, derived from the holder STLs
    - New meshes/Servo-9g.stl (scripts/make_servo_stl.py): SG90/MG90S-class 9 g servo,
    origin on the output shaft at the body top face. Size from the holder pockets
    (23.0 x 12.2 / 23.0 x 12.1 mm) and the bottom holder's coaxial pin (shaft 5.85 mm
    from the pocket end).
    - xacro: reusable servo_9g visual macro; pan + tilt servos, and elbow servos (elbow
    holder is the same part as the head bottom holder; shaft on the bicep axis to
    0.1 mm). No arm joint moved.
    - Head re-seated from mating features: bottom holder (pocket up, pin in the beam's
    head hole) on new fixed head_base_link; pan joint on the pan shaft at its to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
    [Servo-9g.stl, pibob.urdf.xacro]
2026-09-28 arms: put every arm joint origin on its physical pin (parts unmoved)
    - pin_check.py fits the cylindrical features in the STLs: DS3218 holders carry a
    dia-5.8 pin coaxial with the servo shaft; driven U-brackets have a dia-21 horn
    seat + dia-9 hub hole and a dia-6 pin hole; 9 g elbow has a dia-4.7 pin.
    - shoulder_rot / shoulder_lift / arm_rot / bicep origins moved onto the pin root
    (moved 14.3 / 19.5 / 57.8 / 6.5 mm); every visual and child-joint origin
    re-expressed so zero-pose geometry is identical (max vertex displacement 0.0 mm).
    Axis angle vs pin 0.000 deg everywhere; lift_pivot_in/up knobs removed.
    - Reports URDF part-seating errors the pins expose (not applied - would move par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
    [pibob.urdf.xacro]
